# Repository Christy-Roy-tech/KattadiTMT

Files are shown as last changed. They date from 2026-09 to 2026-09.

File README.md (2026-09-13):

git (1)

# Pappadam Plucker

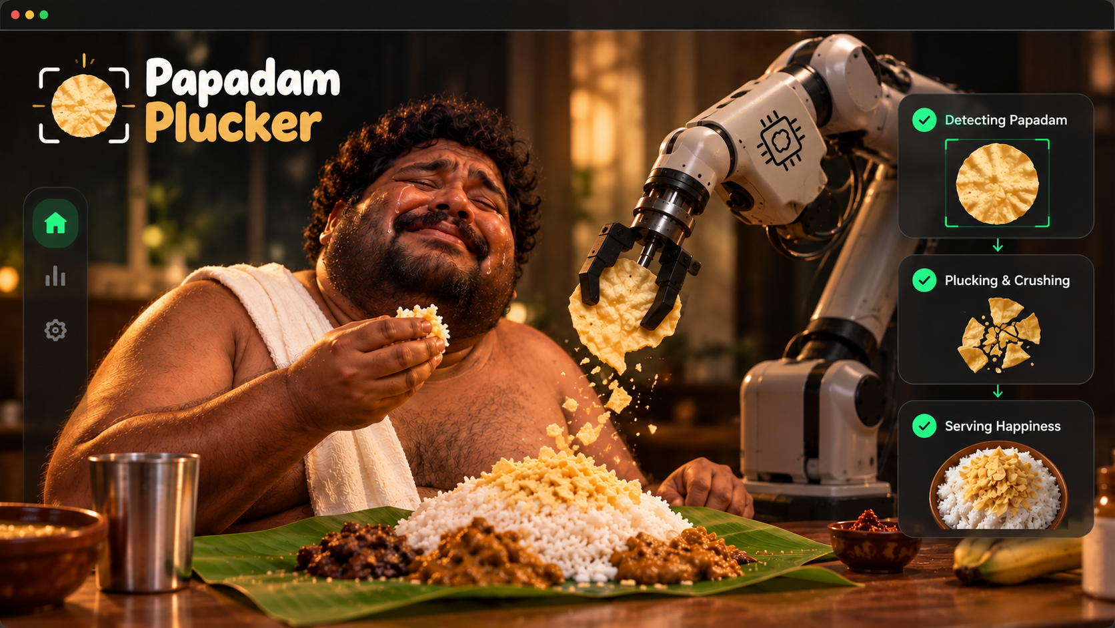
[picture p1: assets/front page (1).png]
Pappadam Plucker Front Page


> An unnecessarily advanced robotic system that detects a pappadam, locks onto it, and crushes it before it can peacefully join your rice and curry.

## Basic Details

### Team Name: KattadiTMT: Ith Kaatath Adilla

### Team Members
- Team Lead: Mekha Rachel — Saintgits College of Engineering
- Member 2: Christy Roy — Saintgits College of Engineering

### Project Description

We are KattadiTMT, presenting the **Autonomous Pappadam Plucker**: a 6-axis robotic arm that automates the deeply exhausting task of crushing pappadam before eating.

The system uses an Android phone as an overhead camera, OpenCV-based pappadam detection, a tactical crosshair interface, and a robotic arm with saved coordinates. Once the pappadam is locked onto, the arm moves to a pre-taught crushing position, plays a dramatic crunch sound, and returns safely home.

### The Problem (that doesn't exist)

While eating rice, we often have to crush pappadam before mixing it with rice and curry. This robotic arm helps crush pappadam before eating.

More importantly, it protects humanity from the unbearable inconvenience of using its own fingers.

### The Solution (that nobody asked for)

A 6-axis robot arm watches a plate through a phone camera like a highly overqualified surveillance system.

1. The phone streams a live view of the plate to Python through IP Webcam.
2. The software learns what the empty plate looks like during calibration.
3. When a pappadam appears, the system checks whether the new object is sufficiently round and pappadam-like.
4. A military-style interface announces `PAPPADAM DETECTED - TARGET LOCKED` and draws a crosshair at the pappadam’s centre.
5. The robotic arm moves smoothly to a pre-saved pluck position.
6. The gripper/crusher closes, a crunch sound plays, and the pappadam is eliminated.
7. The arm returns to its safe home position, ready for its next extremely important mission.

## Technical Details

### Technologies/Components Used

#### For Software
- Python 3 — main application language
- CustomTkinter — dark-glass robot control interface
- OpenCV (`opencv-python`) — phone-camera capture, calibration, background subtraction, object detection, and tactical crosshair rendering
- NumPy — image-processing calculations
- Pillow (`PIL`) — splash-image handling, CRT-style transition, and Tkinter image rendering
- Pygame — pappadam-crushing sound effect playback
- PySerial — USB serial communication from laptop to ESP32
- IP Webcam (Android app) — turns the phone into a Wi-Fi camera source
- VS Code — development environment
- GitHub — code, documentation, build log, and project story

#### For Hardware
- 6-axis robotic arm, reused and upgraded from an earlier project
- ESP32 microcontroller running the arm firmware
- Adafruit PCA9685 16-channel PWM servo driver
- MG995 servo motors for base rotation, shoulder, and wrist pitch
- SG90 servo motors for elbow, wrist roll, and gripper
- Robotic gripper/crusher mechanism
- ESP8266-based glove controller for optional ESP-NOW manual override
- Android phone running IP Webcam, mounted above the plate
- Custom power module using battery packs, BMS boards, buck converters, rocker switch, and DC barrel connector
- A plate and one unfortunate pappadam

## Implementation

### Installation

```powershell
# Create and activate a project environment
uv venv .venv --python 3.14
.\.venv\Scripts\Activate.ps1

# Install Python requirements
uv pip install opencv-python numpy customtkinter pyserial pillow pygame
```

### Run

1. Power the robot arm using its external servo power system.
2. Connect the ESP32 to the laptop using USB.
3. Connect the Android phone and laptop to the same Wi-Fi network or hotspot.
4. Open IP Webcam on the phone and start the video server.
5. Copy the phone camera URL ending in `/video`.
6. Update the camera URL in the Python file:

```python
PHONE_URL = "http://192.168.132.198:808//video"
```

7. Run the full cinematic application:

```powershell
python kattadi_app.py
```

8. Keep the plate empty during the 2.5-second background calibration.
9. In the control panel, select the correct COM port, click **Connect**, then **Enable System**.
10. Manually position the arm over the plate and click **Save Pluck**.
11. Move the arm to a safe return position and click **Save Unpluck**.
12. Start hunting and place a pappadam in the tray.

## How Detection Works

Colour-only detection was rejected because skin, wood, walls, and random objects can also look pappadam-coloured. Instead, the detector follows these steps:

1. It captures about 2.5 seconds of the empty plate and calculates a median background image.
2. Each new phone-camera frame is compared against that background.
3. Only newly introduced objects become possible targets.
4. A cream/yellow colour filter removes clearly unrelated objects.
5. Contour filters check minimum area, circularity, aspect ratio, and convex-hull solidity.
6. The pappadam centre must remain stable for several frames before the system declares a target lock.

This reduces false targets caused by hands, plate reflections, shadows, rectangular objects, and random background clutter.

## How the Full Sequence Works

1. The operator manually controls and calibrates each robot joint from the dark-glass control panel, and saves **Pluck** (over the crushing area) and **Unpluck** (safe home position) presets.
2. Both presets are written to disk immediately (`coordinates.txt` / `saved_coordinates.json`), so they survive an app restart — the operator only has to calibrate once.
3. Launching the app shows a full-screen splash image with a slowly blinking **"PRESS ANY KEY TO CONTINUE"** prompt.
4. A key press or click plays a short VHS/static transition effect, like an old CRT monitor powering on.
5. The live phone-camera feed appears inside a detective/tactical-style HUD (scanline sweep, corner brackets, a blinking REC indicator, live clock) — deliberately with no drawn crosshair or green markers.
6. A background theme plays on loop while the system silently scans for a pappadam.
7. Once a target holds steady for enough consecutive frames, the view smoothly zooms in on it and overlays a custom aim graphic, with a "TARGET ACQUIRED" banner.
8. A short celebration video plays.
9. In the background, the saved Pluck coordinates are sent to the arm; the crunch happens as the gripper closes.
10. After a short pause, the saved Unpluck coordinates return the arm to home.
11. After 5 seconds showing "MISSION ACCOMPLISHED", the whole app resets to the splash screen and loops, ready for the next pappadam.

### Detection Region (ROI)
On first launch, the app asks you to drag a rectangle tightly around the plate. Everything outside that box is ignored for both calibration and detection — this was added specifically to stop workbench clutter (tools, wires, reflections) from ever being mistaken for a pappadam. The selection is saved (`saved_roi.json`) so you only do it once per camera position.

## Project Documentation

### Screenshots

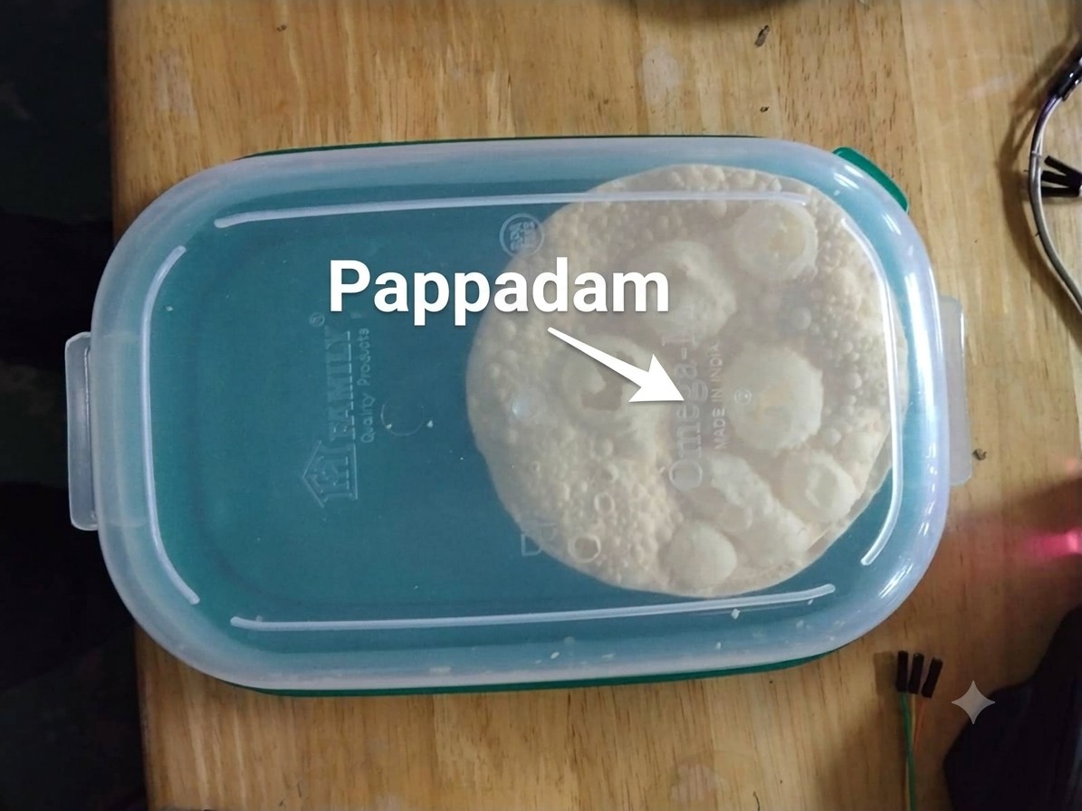
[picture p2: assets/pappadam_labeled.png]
Pappadam target


*The pappadam target placed inside the detection tray before the crushing mission begins.*

*The OpenCV detector locks onto the pappadam and draws a crosshair at its calculated centre.*

*The dark-glass control interface is implemented in the integrated Python application.*

### Workflow Diagram

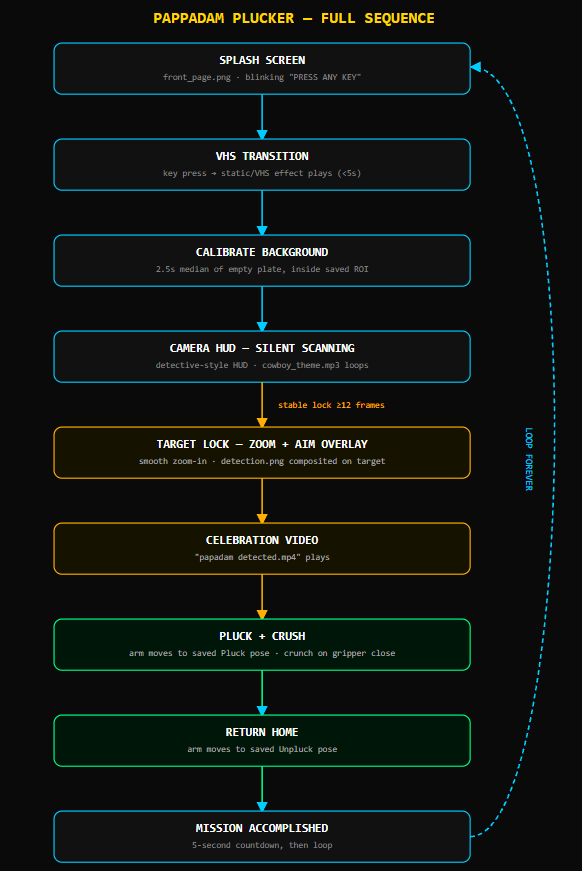
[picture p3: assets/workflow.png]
Workflow Diagram


*Splash screen → VHS transition → empty-plate calibration → silent scanning (cowboy theme) → target lock with zoom + aim overlay → celebration video → pluck + crush → return home → 5-second reset → loop forever.*

## Hardware Documentation

### Circuit & Power Module

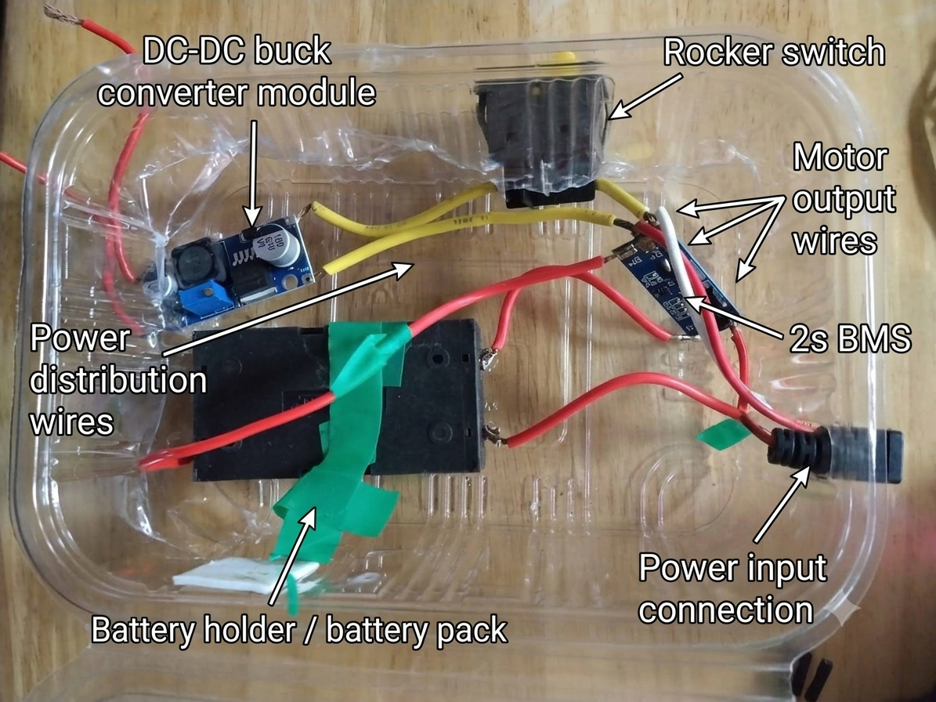
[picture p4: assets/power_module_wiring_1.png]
Power module version 1


*First power-module build using a DC-DC buck converter, rocker switch, 2S BMS, and motor-output wiring in a repurposed plastic container.*

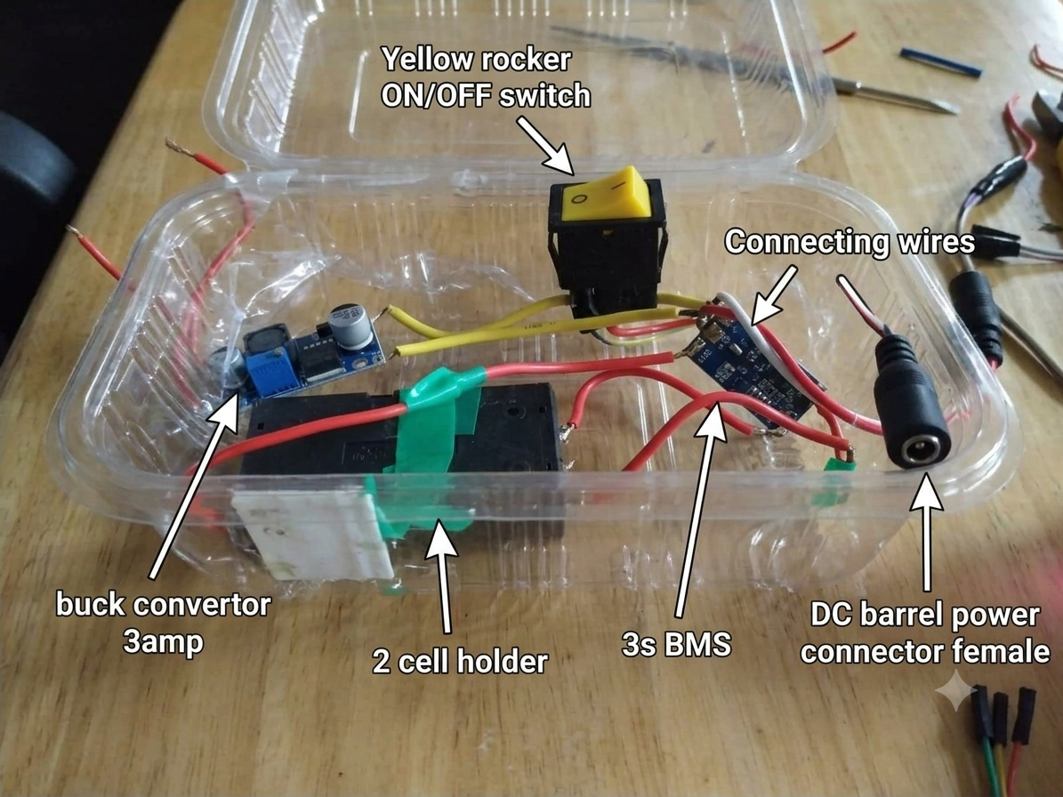
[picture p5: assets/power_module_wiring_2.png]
Power module version 2


*Second power-module revision with a 3S BMS, 3A buck converter, DC barrel connector, and cleaner cable routing.*

### Build Photos

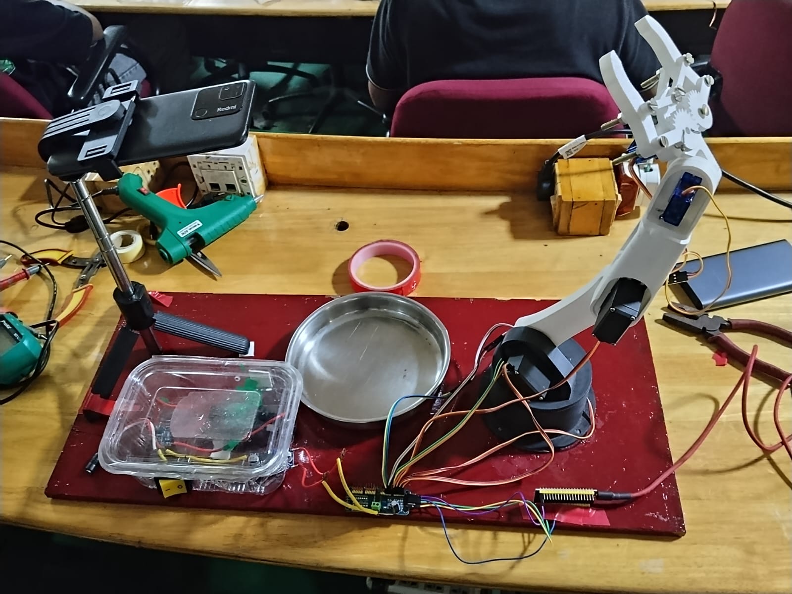
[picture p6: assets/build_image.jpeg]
Final build model


*The completed Autonomous Pappadam Plucker ready for testing.*

## Build Log

### Session 1 — September 12, 2026
- Camera-only detector tested standalone: IP Webcam feed and background-calibration workflow tested.
- Arm-only control panel tested standalone: manual axes, COM-port scanning, saved pluck pose, and saved return pose implemented.
- Assets prepared: Intro splash screen ready; crush sound and final demo video pending.
- Main challenge: naive colour-only detection matched almost anything cream-coloured (skin, wood, walls) — switched to background subtraction instead.

### Session 2 — September 13, 2026
- Phone camera stream configured using IP Webcam; detector compares each live frame against a calibrated empty-plate background.
- Contour filters added for object area, circularity, aspect ratio, and solidity.
- Main challenge: raw contour circularity was unreliable — a pappadam's own dimpled texture makes its outline jagged, tanking the circularity score even on a correctly-detected blob.
- Fix: circularity is now measured against the convex hull's perimeter instead of the raw contour, which ignores that texture noise.
- Main challenge #2: workbench clutter (tools, wires, a curved plastic-lid reflection) occasionally got merged into the same blob as the pappadam.
- Fix: added a one-time "drag a box around the plate" region-of-interest step at startup — everything outside it is now ignored entirely.
- Result: detection locks reliably and repeatably on the actual pappadam.

### Session 3 — Integration
- Robot-arm control panel and vision system merged into a single application.
- Pluck/Unpluck coordinates are now saved to disk (`coordinates.txt` / `saved_coordinates.json`) instead of only living in memory, so calibration work survives an app restart.
- Confirmed working: saving a Pluck pose (`{'A1': 172, 'A2': 52, 'A3': 0, 'A4': 0, 'G': 0}`) and Unpluck pose (`{'A1': 0, 'A2': 9, 'A3': 0, 'A4': 0, 'G': 0}`) both persist correctly.
- Full cinematic experience built: splash screen → VHS transition → detective-style HUD scanning → zoom-and-lock with aim overlay → celebration video → pluck/crush/unpluck → 5-second reset loop.

### Session 4 — Final testing
- Full detection → target lock → pluck → crunch sound → return cycle: `[update after test]`
- Repeatability test: `[update number of runs and successful runs]`
- Final detection tuning values: `[update after final test]`
- Final improvements: `[update with final changes]`

## Project Demo

### Video

[Final demo video](./assets/demo.mp4)

*Shows empty-plate calibration, pappadam detection, crosshair target lock, robotic movement to the saved pluck position, crunch sound playback, and safe return to the home position.*

### Additional Demo

[Early Attempt Demo](https://github.com/Christy-Roy-tech/KattadiTMT/blob/main/assets/failed_attempt_demo.mp4)

*An early test of the full sequence. It is kept as evidence of the debugging process and will be followed by the final working demo.*

## Team Contributions

- **Mekha Rachel:** Python development, OpenCV pappadam detection, phone-camera integration, CustomTkinter control interface, robot serial communication, UI design, visual targeting system, and documentation.
- **Christy Roy:** Robot-arm construction, mechanical setup, servo wiring, power-module development, ESP32/PCA9685 setup, arm calibration, physical testing, and demo support.

---

Read a midnight unfilltered work experience we had during Tinkerhub useless project journal.md

Made with ❤️ at TinkerHub Useless Projects




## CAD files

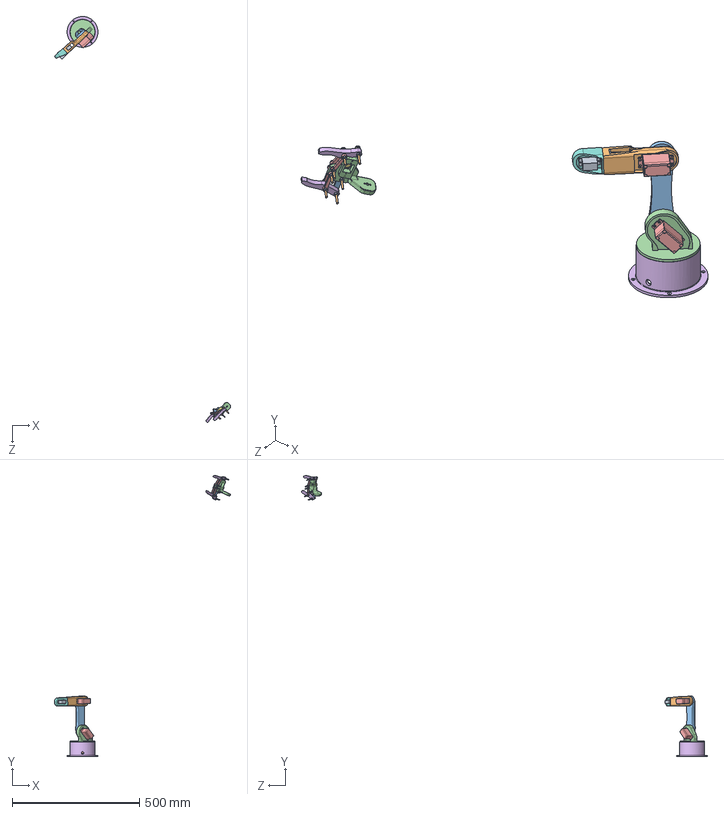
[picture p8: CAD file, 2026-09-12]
3D_Model/5 DOF Robotic Arm with 1 DOF Mechanical Gripper.SLDASM
693.2 x 1103.9 x 1595.2 mm
Base of Robotic Arm
Servo Motor x 3
Waist 1
Link_1
Link_2
Blue Servo x 2
Link_3
Gear 2
Gripper x 2
Gripper Link x 4
Robot Gripper Design
Gear 1
Nut x 7
NUT m3 x 7

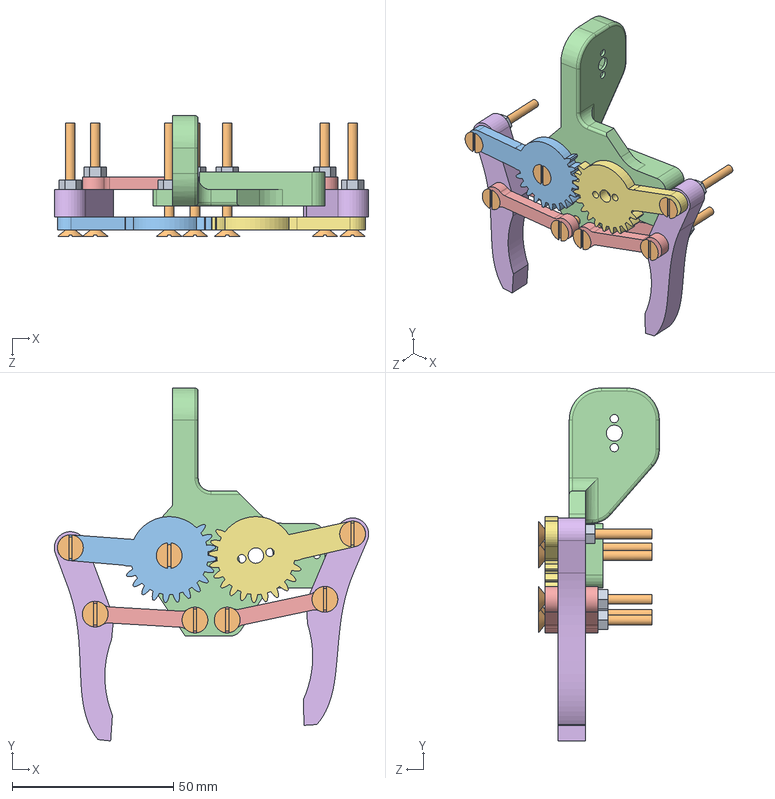
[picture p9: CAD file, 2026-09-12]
3D_Model/Gripper assembly.SLDASM
97.6 x 109.5 x 37.5 mm
Gear 2
Gripper x 2
Gripper Link x 4
Robot Gripper Design
Gear 1
Nut x 7
NUT m3 x 7

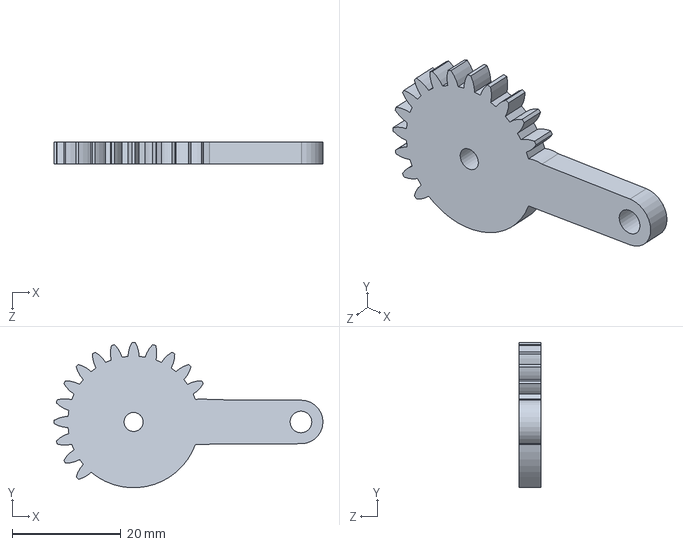
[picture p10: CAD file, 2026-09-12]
3D_Model/Gear 1.SLDPRT
49.4 x 26.7 x 4.00 mm

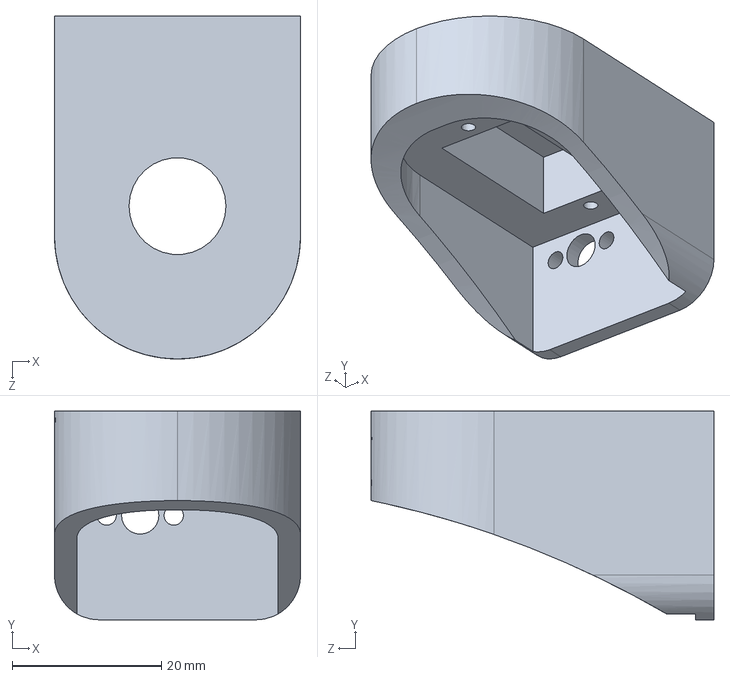
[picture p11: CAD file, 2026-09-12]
3D_Model/Link_3.SLDPRT
33.0 x 28.0 x 46.0 mm

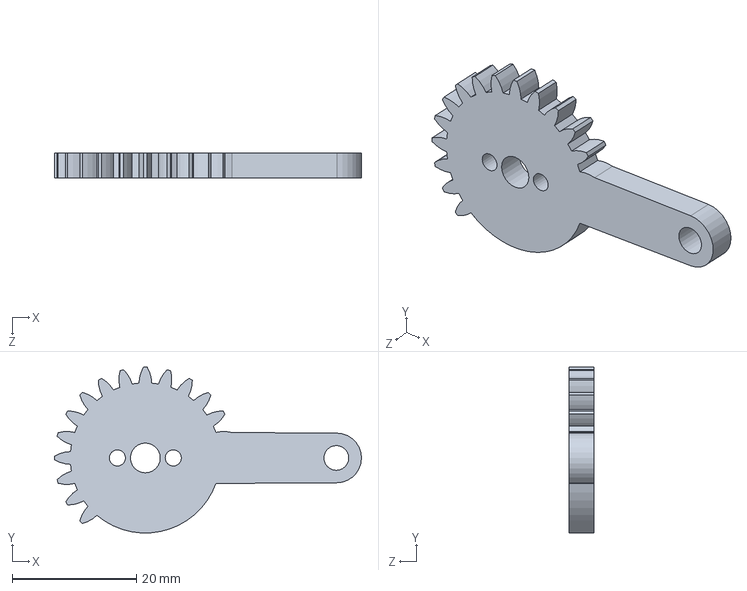
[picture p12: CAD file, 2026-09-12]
3D_Model/Gear 2.SLDPRT
49.4 x 26.7 x 4.00 mm

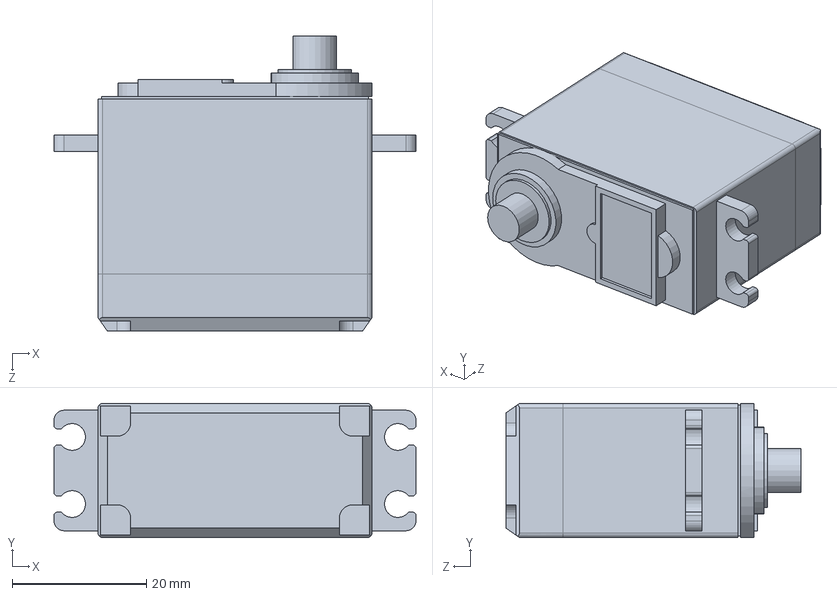
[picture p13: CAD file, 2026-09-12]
3D_Model/Servo Motor.SLDPRT
54.0 x 20.0 x 44.0 mm

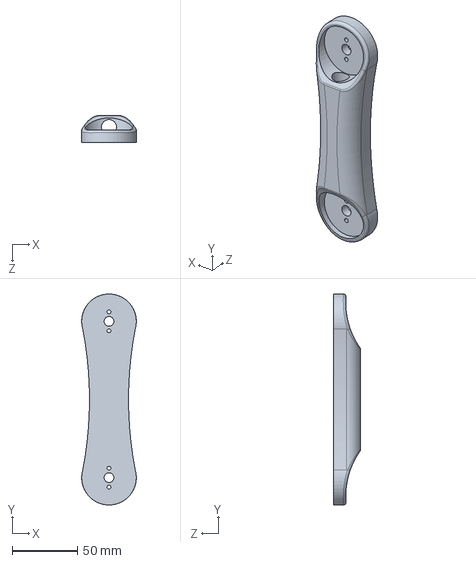
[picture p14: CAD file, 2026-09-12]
3D_Model/Link_1.SLDPRT
42.0 x 162.0 x 21.0 mm

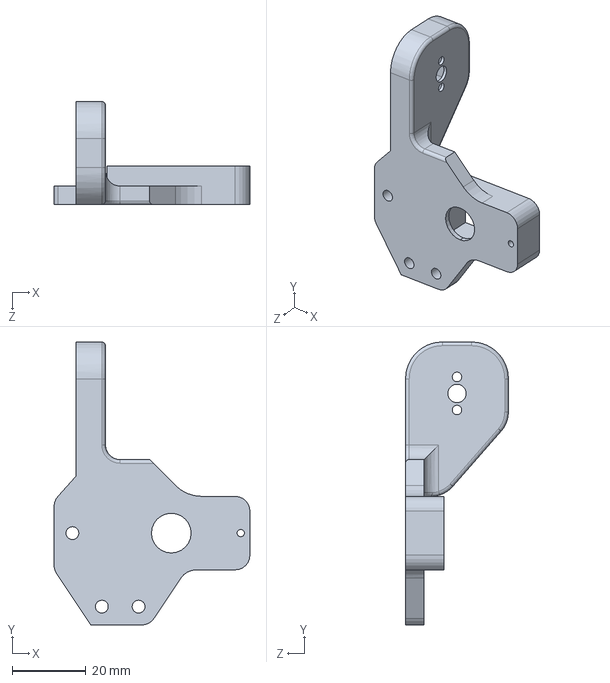
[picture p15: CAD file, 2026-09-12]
3D_Model/Robot Gripper Design.SLDPRT
53.3 x 77.0 x 28.0 mm

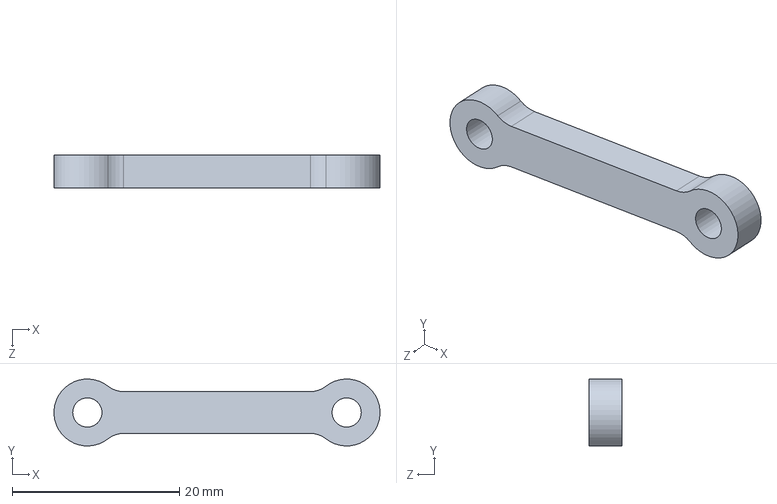
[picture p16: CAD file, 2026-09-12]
3D_Model/Gripper Link.SLDPRT
39.0 x 7.99 x 4.00 mm

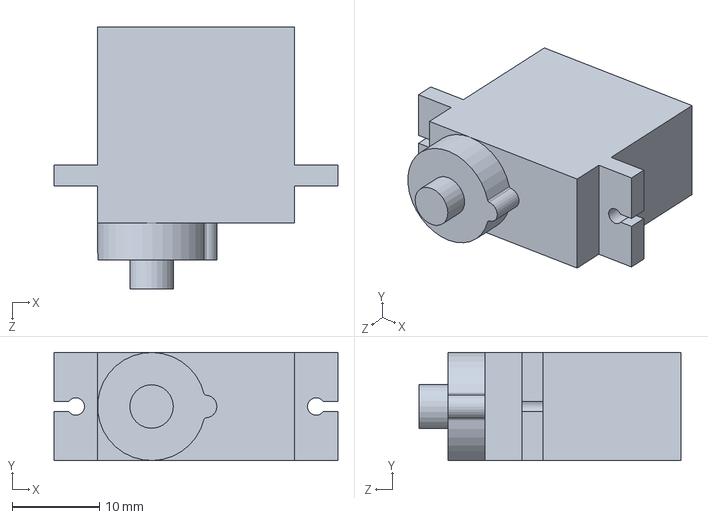
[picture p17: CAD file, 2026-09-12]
3D_Model/Blue Servo.SLDPRT
32.6 x 12.4 x 30.0 mm

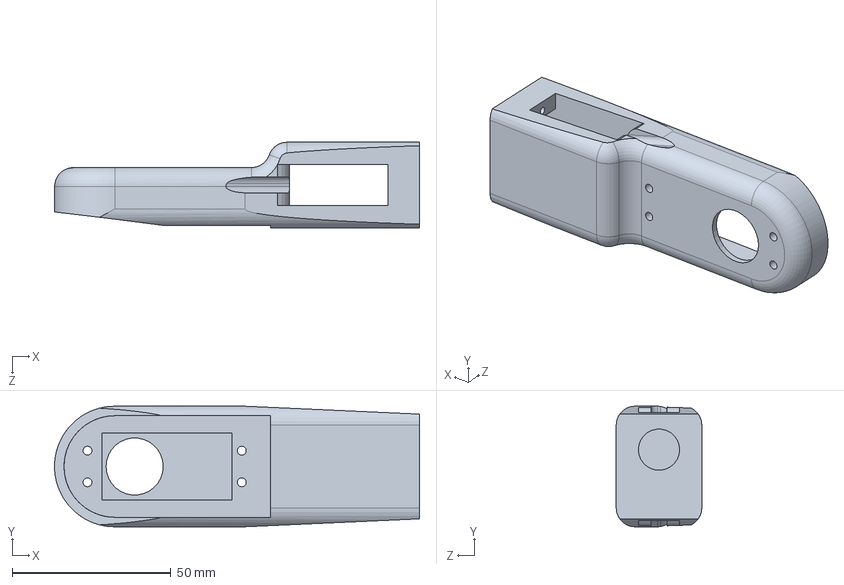
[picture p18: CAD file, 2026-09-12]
3D_Model/Link_2.SLDPRT
115.0 x 38.0 x 27.0 mm

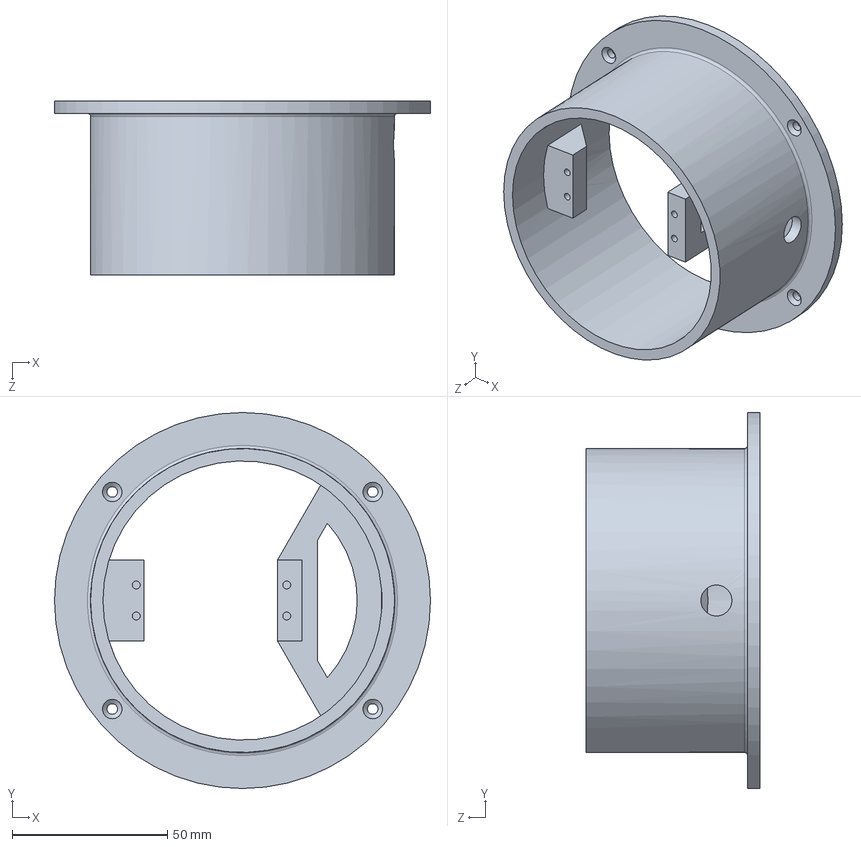
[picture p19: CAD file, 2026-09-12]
3D_Model/Base of Robotic Arm.SLDPRT
121.2 x 121.2 x 56.0 mm

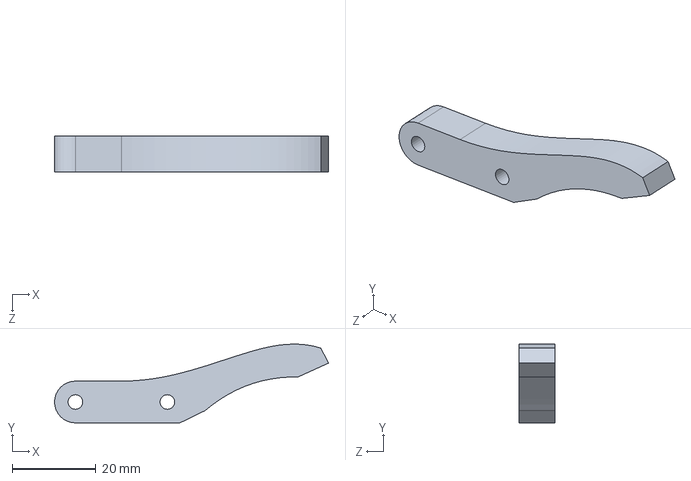
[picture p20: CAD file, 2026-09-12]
3D_Model/Gripper.SLDPRT
65.6 x 18.9 x 8.50 mm

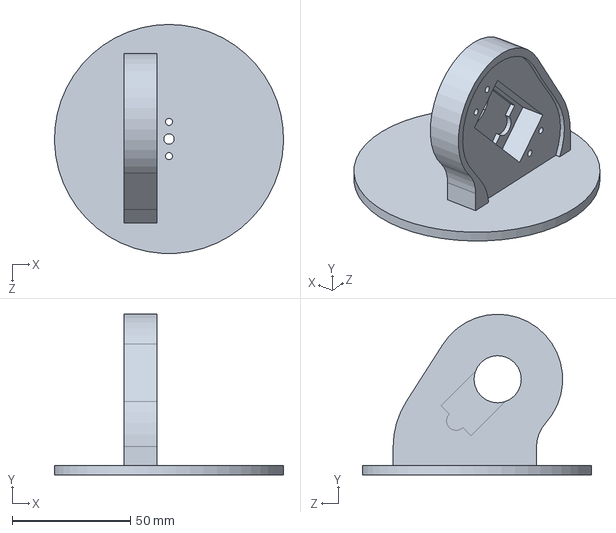
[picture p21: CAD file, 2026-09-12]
3D_Model/Waist 1.SLDPRT
97.0 x 68.0 x 97.0 mm

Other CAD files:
3D_Model/NUT m3.SLDPRT
3D_Model/Nut.SLDPRT

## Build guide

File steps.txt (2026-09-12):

KATTADITMT GUI - WINDOWS SETUP STEPS

These commands install the dependencies and run the Python GUI.
Use PowerShell in the folder that contains this file.

1. Check that Python is installed

py --version

Python 3.10 or newer is recommended. If the command is not found, install Python from https://www.python.org/downloads/ and enable "Add Python to PATH" during installation.

2. Open the project folder

cd "C:\Users\YourName\KattadiTMT\KattadiTMT"

Replace C:\Users\YourName\KattadiTMT\KattadiTMT with the actual project folder path on the laptop.

3. Create a virtual environment

py -m venv .venv

If .venv already exists, this command can be skipped.

4. Install the required packages

.\.venv\Scripts\python.exe -m pip install --upgrade pip
.\.venv\Scripts\python.exe -m pip install customtkinter pyserial Pillow

Package/import mapping:
- customtkinter -> import customtkinter
- pyserial -> import serial
- Pillow -> from PIL import Image, ImageEnhance

5. Verify all dependencies

.\.venv\Scripts\python.exe -c "import customtkinter, serial, serial.tools.list_ports; from PIL import Image, ImageEnhance; print('Dependencies installed successfully')"

6. Run the GUI

.\.venv\Scripts\python.exe ".\Graphic User Inteface.py"

The GUI uses a COM port to communicate with the robot. Connect the controller and select its COM port in the application before pressing Connect.

7. Optional: activate the virtual environment first

.\.venv\Scripts\Activate.ps1
python -m pip install --upgrade pip
python -m pip install customtkinter pyserial Pillow
python ".\Graphic User Inteface.py"

If PowerShell blocks activation, use the direct .venv\Scripts\python.exe commands above. Activation is not required.

8. If the COM port is not detected

Run this command to list available serial ports:

.\.venv\Scripts\python.exe -c "import serial.tools.list_ports; print([p.device for p in serial.tools.list_ports.comports()])"

Install the USB driver for the robot controller if no COM port appears.

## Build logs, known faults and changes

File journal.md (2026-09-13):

---
title: "The Pappadam Plucker Journal"
layout: default
---

# We Built a Robot to Crush Pappadam. It Fought Us the Whole Way.

*A KattadiTMT build story — TinkerHub Useless Projects 3.0*

Pappadam Plucker Front Page

There is no shortage of real problems in the world. We picked none of them. Instead, we
decided that the two extra seconds it takes to crush a pappadam by hand before mixing it
into rice and curry was an injustice worth solving with a 6-axis robotic arm, a phone
camera, computer vision, and — eventually — a cowboy-themed soundtrack.

This is the story of how that went.

---

## Day 1 — "It Detects Everything As Pappadam"

We already had a 6-axis arm sitting around from an earlier project, so the hardware side
felt like a head start. The plan was simple: point a phone camera at a plate, use OpenCV
to spot a pappadam, and have the arm crush it.

The first version of the detector used plain color filtering — "if it's cream-and-yellow,
it's probably a pappadam." It was not probably a pappadam. It was hands, wood, walls, and
at one point what we're fairly sure was a wall socket. The HSV range we'd picked accepted
almost anything under normal lighting.

**Learning #1:** color alone is never enough for real-world object detection. You need
something that captures *what changed*, not just *what color it is*.

**The fix:** background subtraction. Capture the empty plate first, then only look at
pixels that changed from that reference. Suddenly the detector stopped hallucinating
pappadams out of furniture.

> 🖼️ *Insert: screenshot of the "detects everything" mask next to the fixed version*

## Day 2 — The Case of the Missing Keypress

Once background subtraction was in, we needed to calibrate it — press a key with the
plate empty, then place the pappadam. Except... it never seemed to calibrate. Turns out
`cv2.waitKey()` only listens when its own window has focus, and we kept typing into the
terminal instead of clicking the video window first.

The fix that actually mattered here wasn't clever, it was just removing the human step
entirely: the app now auto-calibrates for 2.5 seconds the moment it starts, using the
*median* of many frames instead of one single (possibly glare-ruined) snapshot. No more
clicking the right window at the right time.

## Day 3 — The Circularity Crisis

This was the one that nearly broke us.

The detector was finding *something* the right size and roughly the right shape, but
kept rejecting it — circularity scores like `0.05`, `0.06`, `0.14`, when we needed at
least `0.4`. A pappadam is basically a circle. Why did the math think it was a straight
line?

We added debug logging that printed out exactly why the best candidate got rejected
every second, and stared at the numbers until it clicked: **a pappadam is not smooth.**
All those little dimples, bubbles, and bumps on its surface show up as gaps and notches
in the detection mask, turning a clean circular outline into something jagged. Circularity
is calculated from perimeter — and a jagged perimeter is a *much* longer perimeter for
the same area, which tanks the score even for an object that's obviously round to a
human eye.

**The fix:** measure circularity against the *convex hull* of the shape instead of its
raw, texture-noisy outline. The hull smooths right over the dimples. Circularity scores
jumped from `0.05` to `0.6–0.8` on the very next test — same pappadam, same lighting,
completely different number, just because we were measuring it correctly.

> 🎬 *Insert: the failed_attempt_demo.mp4 clip here — this is the debugging phase it
> came from.*

## Day 4 — "Other Parts" Kept Getting Detected

With circularity fixed, a new problem showed up: sometimes a tool on the workbench, or a
reflection off the plate's plastic lid, would get merged into the same blob as the
pappadam, throwing off the shape checks in the other direction.

**The fix:** at startup, drag a box around just the plate. Everything outside it stops
existing as far as the detector is concerned. Simple, a little inelegant, extremely
effective — sometimes the right fix isn't a smarter algorithm, it's just not looking at
the parts of the picture you don't care about.

## Day 5 — Building the Body

While the vision side was being debugged, the hardware side was evolving in parallel.
The first power module revision ran off a 2S battery pack through a small buck converter:

Power module v1

It worked, but the wiring was tight and the power margin was thinner than we wanted. The
second revision moved to a 3S pack, a proper 3A buck converter, and a real DC barrel
connector instead of loose leads:

Power module v2

**Learning:** the first working version of anything is rarely the version you keep. Both
the detector and the power module went through a "make it work" pass and then a
"make it work *properly*" pass.

## Day 6 — Making It Permanent

Small but important fix: the arm's saved Pluck and Unpluck coordinates were living only
in memory. Close the app, lose the calibration. We added persistence to
`coordinates.txt` / `saved_coordinates.json` so calibration only has to happen once, ever
— confirmed working:

```
✅ Pluck Saved: {'A1': 172, 'A2': 52, 'A3': 0, 'A4': 0, 'G': 0}
✅ Unpluck Saved: {'A1': 0, 'A2': 9, 'A3': 0, 'A4': 0, 'G': 0}
```

## Day 7 — Going Full Cinematic

At this point detection was solid and the arm was reliable, so naturally we decided the
project needed a splash screen, a VHS-static transition, a detective-noir HUD with a
scanline sweep and a blinking REC light, a cowboy-themed soundtrack, a custom
target-lock graphic, and a celebration video — because if you're going to build an
unnecessary robot, you should not stop at "functional."

The final sequence: splash → press any key → VHS transition → live tactical camera feed
→ silent scanning (cowboy theme looping) → zoom-in lock with aim overlay → celebration
clip → pluck → crunch → return home → 5-second countdown → loop forever.

> 🎬 *Insert: full end-to-end run once recorded*
> 🖼️ *Insert: GIF of the zoom-to-lock moment — this is the most visually striking part,
> worth its own GIF*

Live build session at the venue

*Debugging the detector live at the venue — the laptop screen shows the actual camera
feed and code side by side, arm and bowl sitting right there on the desk.*

## Day 8 — It Actually Works

[Final demo](./assets/final_demo.mp4) — the full cycle, recorded.

*(fill in — what it felt like watching it complete a full cycle for the first time)*

---

## Team Contributions

- **Mekha Rachel** — Python development, OpenCV detection pipeline (and all of its
  debugging), CustomTkinter control interface, serial communication, cinematic app
  integration, documentation.
- **Christy Roy** — Robot arm construction, mechanical setup, servo wiring, power module
  design and revisions, ESP32/PCA9685 firmware, arm calibration, physical testing.

## What We'd Do Differently

*(fill in — what surprised you, what you'd tell a team starting this from scratch)*

---

Made with ❤️, background subtraction, and an unreasonable amount of confidence at
TinkerHub Useless Projects 3.0.

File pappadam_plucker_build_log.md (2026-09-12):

# Autonomous Pappadam Plucker — Build Log
**Team:** KattadiTMT — TinkerHub Useless Projects 3.0

Keep this updated as you complete each step of the build guide. Copy the finished
sections straight into your submission README when you're done.

---

## Problem / Solution (from your template)
> While eating rice, we often have to crush pappadam first before mixing it with
> rice and curry. This robotic arm helps us crush pappadam before eating.

**Solution:** A 6-axis robotic arm watches a plate through a phone camera. When it
spots a pappadam, it locks a targeting crosshair on it, moves to a pre-taught
"pluck" position, crushes it, plays a crunch sound effect, and returns home —
fully hands-free.

---

## Technologies / Components Used

**Software**
- Python 3 — main application language
- `customtkinter` — dark-glass control panel UI
- `OpenCV` (`opencv-python`) — camera capture + pappadam detection
- `NumPy` — image math for the background-subtraction detector
- `Pillow` (PIL) — image handling for the intro image, CRT transition, and embedding video frames in the Tkinter UI
- `pygame` — plays the crushing sound effect
- `pyserial` — USB serial link from the control panel to the ESP32
- IP Webcam (Android app) — turns a phone into a Wi-Fi camera source

**Hardware**
- 6-axis robotic arm (reused from an earlier project)
- ESP32 microcontroller running the arm firmware
- Adafruit PCA9685 PWM servo driver (16-channel)
- Servos: MG995 (base rotation, shoulder, wrist pitch), SG90 (elbow, wrist roll, gripper)
- ESP8266-based glove controller (optional manual override input, via ESP-NOW)
- Phone (any Android device with IP Webcam installed), mounted to view the plate

---

## How Detection Works
Instead of matching pappadam by color alone (too easy to confuse with skin, wood,
walls, etc.), the detector:
1. Captures ~2.5 seconds of the **empty plate** as a reference "background" (median of many frames, so one bad frame doesn't wreck it).
2. Compares each new frame against that background — anything that changed is a candidate object.
3. Filters candidates by circularity, aspect ratio, and convex-hull solidity (rejects hands, shadows, non-round objects).
4. Requires the detected center to stay within a small pixel radius for ~15 consecutive frames before it's considered "locked" — this debounce stops a single noisy frame from firing the arm.

## How the Pluck Sequence Works
1. Operator manually jogs the arm to a pluck position (over the plate, gripper closed enough to crush) and clicks **Save Pluck**.
2. Operator jogs to a safe home/away position and clicks **Save Unpluck**.
3. Clicking **Start Hunting** runs: intro image → CRT power-off transition → auto-calibration → live scanning.
4. On a stable lock, the arm animates to the saved pluck pose; the crush sound fires the instant the gripper starts closing.
5. After a short pause, the arm animates back to the saved unpluck pose, and scanning resumes automatically.

---

## Build Log

### Session 1 — [fill in date]
- [ ] Camera-only detector tested standalone — works? Y/N, notes:
- [ ] Arm-only control panel tested standalone — works? Y/N, notes:
- [ ] Assets ready (intro image, crush sound)?

### Session 2 — [fill in date]
- [ ] Merged app runs, intro + transition display correctly
- [ ] Calibration completes without errors
- [ ] First successful auto-lock
- [ ] Detection tuning notes (what you changed, why):

### Session 3 — [fill in date]
- [ ] Full pluck → crush sound → return cycle confirmed
- [ ] Repeatability tested (how many runs, success rate)
- [ ] Final tuning values used:

---

## Screenshots (add at least 3)
Camera detection working
*Caption: crosshair locked onto a pappadam during standalone detector testing*

Arm control panel
*Caption: the dark-glass control UI with pluck/unpluck presets saved*

Full system running
*Caption: the integrated app mid-hunt, showing the military-HUD scanning view*

## Workflow Diagram
*(Use the state-machine diagram from earlier in the build conversation: Intro → CRT transition → Scanning → Target locked → Pluck triggered → Return to home → back to Scanning)*

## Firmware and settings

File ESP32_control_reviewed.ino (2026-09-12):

#include <Wire.h>
#include <Adafruit_PWMServoDriver.h>
#include <WiFi.h>
#include <esp_now.h>

Adafruit_PWMServoDriver pwm = Adafruit_PWMServoDriver();

// --- PCA9685 Channel Mapping ---
#define CH_BASE360   0  
#define CH_SHOULDER  1  
#define CH_ELBOW     2  
#define CH_WRIST_P   3  
#define CH_WRIST_R   4  
#define CH_GRIPPER   5  

// --- 1. BASE 360 CALIBRATION ---
#define BASE360_STOP   280 
#define BASE360_LEFT   330 
#define BASE360_RIGHT  210 

// --- 2. STANDARD PULSE LIMITS ---
#define PULSE_MIN  150 // ~0 degrees
#define PULSE_MAX  600 // ~180 degrees

// --- 3. SHOULDER CALIBRATION (Restored Safe Limits) ---
#define SHOULDER_MIN_TICK 260
#define SHOULDER_MAX_TICK  450

// --- 4. GRIPPER CALIBRATION ---
#define GRIPPER_CLOSE_TICK 200 
#define GRIPPER_OPEN_TICK  450 

bool isPowered = false;      
bool gloveOverride = false;  
bool lastGloveState = false; 
uint8_t lastPreset = 0;

// Must match the ESP8266 Glove struct exactly!
typedef struct struct_message {
    uint8_t gloveActive;  
    int16_t pitch;        
    int16_t roll;         
    uint8_t preset;       
} struct_message;

struct_message gloveData;

// Helper: Standard 0-180 angle to PCA9685 pulse (Used by Elbow, Wrist, etc.)
int angleToPulse(int ang) {
  ang = constrain(ang, 0, 180);
  return map(ang, 0, 180, PULSE_MIN, PULSE_MAX);
}

// Helper: Dedicated to the Shoulder to enforce safe physical gear limits!
int shoulderAngleToPulse(int ang) {
  ang = constrain(ang, 9, 170); // Python dashboard slider limits
  return map(ang, 9, 170, SHOULDER_MIN_TICK, SHOULDER_MAX_TICK);
}

// --- ESP-NOW CALLBACK (UPDATED FOR ESP32 V3 CORE) ---
void OnDataRecv(const esp_now_recv_info * info, const uint8_t *incomingData, int len) {
  memcpy(&gloveData, incomingData, sizeof(gloveData));
  
  // 1. Detect if the Glove Switch was just flipped ON or OFF
  if (gloveData.gloveActive == 1) {
    if (!lastGloveState) {
      Serial.println("GLOVE:ON"); // Tells Python to Lock the UI!
      lastGloveState = true;
    }
    gloveOverride = true;
    
    // 2. Detect Presets and trigger Python!
    if (gloveData.preset == 1 && lastPreset != 1) {
      Serial.println("GLOVE:PLUCK"); 
      lastPreset = 1;
    } 
    else if (gloveData.preset == 2 && lastPreset != 2) {
      Serial.println("GLOVE:UNPLUCK"); 
      lastPreset = 2;
    }
    else if (gloveData.preset == 0) {
      lastPreset = 0; // Reset when hand is flat
      
      // 3. Manual Glove Tracking (when not running a preset)
      int shoulderAng = map(gloveData.pitch, -45, 45, 170, 9); 
      // Safely route tracking data through the dedicated Shoulder helper
      pwm.setPWM(CH_SHOULDER, 0, shoulderAngleToPulse(shoulderAng));

      int wristRollAng = map(gloveData.roll, -45, 45, 0, 180);
      pwm.setPWM(CH_WRIST_R, 0, angleToPulse(wristRollAng));
      
      // Keep Elbow safely stable at a resting 25 degrees during hand tracking
      pwm.setPWM(CH_ELBOW, 0, angleToPulse(25));
    }
    
  } else {
    // Switch is OFF
    if (lastGloveState) {
      Serial.println("GLOVE:OFF"); // Tells Python to Unlock the UI!
      lastGloveState = false;
    }
    gloveOverride = false;
    lastPreset = 0;
  }
}

void setup() {
  Serial.begin(115200);
  
  pwm.begin();
  pwm.setOscillatorFrequency(27000000);
  pwm.setPWMFreq(50);

  // Turn off all servos and stop the base IMMEDIATELY — before WiFi/ESP-NOW
  // get a chance to add delay, and guaranteed to run even if ESP-NOW below fails.
  for(int i=0; i<16; i++) pwm.setPWM(i, 0, 0);
  pwm.setPWM(CH_BASE360, 0, BASE360_STOP);

  // Set device as a Wi-Fi Station for ESP-NOW
  WiFi.mode(WIFI_STA);
  if (esp_now_init() != ESP_OK) {
    Serial.println("Error initializing ESP-NOW");
    return;
  }
  
  // Register the updated callback function
  esp_now_register_recv_cb(OnDataRecv);
  
  Serial.println("SYSTEM READY: 6-AXIS HYBRID (ESP-NOW + PYTHON)");
}

void loop() {
  // --- PYTHON DASHBOARD LOGIC (Via USB Cable) ---
  if (Serial.available() > 0) {
    String cmd = Serial.readStringUntil('\n');
    cmd.trim();

    if (cmd == "P:ON") {
      isPowered = true;
    } else if (cmd == "P:OFF") {
      isPowered = false;
      for(int i=0; i<16; i++) pwm.setPWM(i, 0, 0); 
    } 
    
    // Only obey Python sliders if the Glove Switch is OFF
    else if (isPowered && !gloveOverride) {
      if (cmd == "B:L") pwm.setPWM(CH_BASE360, 0, BASE360_LEFT);
      else if (cmd == "B:R") pwm.setPWM(CH_BASE360, 0, BASE360_RIGHT);
      else if (cmd == "B:S") {
        pwm.setPWM(CH_BASE360, 0, BASE360_STOP); 
        delay(150); 
        pwm.setPWM(CH_BASE360, 0, 0); 
      } 
      // FIXED: Route Shoulder commands exclusively to the safe limits
      else if (cmd.startsWith("A1:")) pwm.setPWM(CH_SHOULDER, 0, shoulderAngleToPulse(cmd.substring(3).toInt()));
      
      else if (cmd.startsWith("A2:")) pwm.setPWM(CH_ELBOW,    0, angleToPulse(cmd.substring(3).toInt()));
      else if (cmd.startsWith("A3:")) pwm.setPWM(CH_WRIST_P,  0, angleToPulse(cmd.substring(3).toInt()));
      else if (cmd.startsWith("A4:")) pwm.setPWM(CH_WRIST_R,  0, angleToPulse(cmd.substring(3).toInt()));
      
      // PERFECTED GRIPPER SLIDER LOGIC
      else if (cmd.startsWith("G:")) {
        int ang = constrain(cmd.substring(2).toInt(), 0, 90);
        pwm.setPWM(CH_GRIPPER, 0, map(ang, 0, 90, GRIPPER_CLOSE_TICK, GRIPPER_OPEN_TICK));
      }
    }
  }
}

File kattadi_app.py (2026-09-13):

#!/usr/bin/env python3
"""
╔══════════════════════════════════════════════════════════════════╗
║   PAPPADAM PLUCKER — CINEMATIC AUTONOMOUS TARGETING SYSTEM      ║
║   Team KattadiTMT                                               ║
║                                                                  ║
║   Full cinematic loop:                                           ║
║   Splash → VHS → Camera HUD → Detect → Celebrate → Pluck/Reset ║
╚══════════════════════════════════════════════════════════════════╝
"""

import tkinter as tk
from PIL import Image, ImageTk, ImageDraw
import cv2
import numpy as np
import threading
import time
import json
import os
import ast
import math

# ─── Optional dependencies ───────────────────────────────────────
try:
    import serial
    import serial.tools.list_ports
    HAS_SERIAL = True
except ImportError:
    HAS_SERIAL = False
    print("[WARN] pyserial not installed — serial commands disabled")

try:
    import pygame
    pygame.mixer.init()
    HAS_AUDIO = True
except Exception:
    HAS_AUDIO = False
    print("[WARN] pygame not available — audio disabled")

# ═════════════════════════════════════════════════════════════════
# FILE PATHS
# ═════════════════════════════════════════════════════════════════
BASE_DIR = os.path.dirname(os.path.abspath(__file__))
REF_DIR  = os.path.join(BASE_DIR, "reference")

FRONT_PAGE_PATH      = os.path.join(REF_DIR, "front page.png")
VHS_VIDEO_PATH       = os.path.join(REF_DIR,
    "Old VHS Effect TV Turn off Vintage static _4K_ Snowman Digital_2160p.mp4")
VHS_OPTIMIZED_PATH   = os.path.join(REF_DIR, "vhs_optimized.mp4")
DETECTION_IMG_PATH   = os.path.join(REF_DIR, "detection.png")
CELEBRATION_VID_PATH = os.path.join(REF_DIR, "papadam detected.mp4")
CELEB_OPTIMIZED_PATH = os.path.join(REF_DIR, "papadam_detected_optimized.mp4")
COWBOY_THEME_PATH    = os.path.join(REF_DIR, "cowboy_theme.mp3")
CELEB_AUDIO_PATH     = os.path.join(REF_DIR, "papadam detected.mp3")
STATIC_AUDIO_PATH    = (
    os.path.join(REF_DIR, "static.mp3")
    if os.path.exists(os.path.join(REF_DIR, "static.mp3"))
    else os.path.join(REF_DIR, "static..mp3")
)
COORDINATES_PATH     = os.path.join(BASE_DIR, "coordinates.txt")
SAVED_CONFIG_PATH    = os.path.join(BASE_DIR, "saved_coordinates.json")
ROI_CONFIG_PATH      = os.path.join(BASE_DIR, "saved_roi.json")

# ═════════════════════════════════════════════════════════════════
# CAMERA CONFIG
# ═════════════════════════════════════════════════════════════════
PHONE_URL  = "http://192.168.132.198:8080/video"
FRAME_SIZE = (900, 650)          # resize every raw frame to this

# ═════════════════════════════════════════════════════════════════
# DETECTION SETTINGS (from pappadam_detector_v6.py)
# ═════════════════════════════════════════════════════════════════
MIN_AREA            = 4000
MIN_CIRCULARITY     = 0.55
MIN_ASPECT_RATIO    = 0.50
MAX_ASPECT_RATIO    = 1.80
MIN_SOLIDITY        = 0.65
DIFF_THRESHOLD      = 30
BG_BLUR             = (7, 7)
AUTO_CALIB_SECONDS  = 2.5
LOWER_PAPPADAM      = np.array([0, 0, 90])
UPPER_PAPPADAM      = np.array([45, 200, 255])
LOCK_STABLE_FRAMES  = 12
LOCK_MOVE_TOLERANCE = 20
ZOOM_STEPS          = 15
ZOOM_HOLD_SECONDS   = 2.0

# ═════════════════════════════════════════════════════════════════
# JOINT CONFIGURATION  (mirrors Python GUI.py slider setup)
# Slider values are stored in coordinates.txt; inversion is
# applied before sending over serial — exactly as the GUI does.
# ═════════════════════════════════════════════════════════════════
JOINTS_CFG = {
    'A1': {'lo': 0,  'hi': 180, 'invert': True},    # Shoulder MG995
    'A2': {'lo': 9,  'hi': 64,  'invert': False},   # Elbow    SG90
    'A3': {'lo': 0,  'hi': 180, 'invert': False},   # Wrist P  MG995
    'A4': {'lo': 0,  'hi': 180, 'invert': True},    # Wrist R  SG90
    'G':  {'lo': 0,  'hi': 90,  'invert': False},   # Gripper
}


# ═════════════════════════════════════════════════════════════════
# DETECTION UTILITIES  (ported from pappadam_detector_v6.py)
# ═════════════════════════════════════════════════════════════════
def get_gray(frame):
    return cv2.GaussianBlur(
        cv2.cvtColor(frame, cv2.COLOR_BGR2GRAY), BG_BLUR, 0)


def hull_circularity(hull, hull_area):
    p = cv2.arcLength(hull, True)
    return (4 * np.pi * hull_area) / (p * p) if p else 0


def detect_pappadam(frame, bg_gray):
    """Full v6 pipeline.  Returns (cx, cy, radius, circularity) or None."""
    if bg_gray is None:
        return None

    gray = get_gray(frame)
    diff = cv2.absdiff(bg_gray, gray)
    _, mask = cv2.threshold(diff, DIFF_THRESHOLD, 255, cv2.THRESH_BINARY)

    ok5  = np.ones((5, 5), np.uint8)
    ok15 = np.ones((15, 15), np.uint8)
    mask = cv2.morphologyEx(mask, cv2.MORPH_OPEN,  ok5)
    mask = cv2.morphologyEx(mask, cv2.MORPH_CLOSE, ok15, iterations=3)

    hsv   = cv2.cvtColor(frame, cv2.COLOR_BGR2HSV)
    cmask = cv2.inRange(hsv, LOWER_PAPPADAM, UPPER_PAPPADAM)
    combined = cv2.bitwise_and(mask, cmask)

    cnts, _ = cv2.findContours(combined, cv2.RETR_EXTERNAL,
                                cv2.CHAIN_APPROX_SIMPLE)

    best, best_area = None, 0
    best_bbox = None
    for c in cnts:
        a = cv2.contourArea(c)
        if a < MIN_AREA:
            continue
        hull  = cv2.convexHull(c)
        ha    = cv2.contourArea(hull)
        sol   = a / ha if ha else 0
        circ  = hull_circularity(hull, ha)
        if circ < MIN_CIRCULARITY:
            continue
        x, y, w, h = cv2.boundingRect(c)
        ar = w / float(h)
        if ar < MIN_ASPECT_RATIO or ar > MAX_ASPECT_RATIO:
            continue
        if sol < MIN_SOLIDITY:
            continue
        if a > best_area:
            best_area = a
            best = c
            best_bbox = (x, y, w, h)

    if best is None:
        return None
    (cx, cy), r = cv2.minEnclosingCircle(best)
    hull  = cv2.convexHull(best)
    ha    = cv2.contourArea(hull)
    circ  = hull_circularity(hull, ha)
    return (int(cx), int(cy), int(r), circ, best_bbox)
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
